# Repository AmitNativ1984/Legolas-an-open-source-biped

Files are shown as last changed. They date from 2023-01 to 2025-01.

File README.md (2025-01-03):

# Legolas - An Open Source Bipedal Robot

Legolas is a mini bipedal robot inspired by the Cassie by Agility Robotics. The project aims to provide an open-source platform for learning and applying reinforcement learning in robotics.

<p align="center">
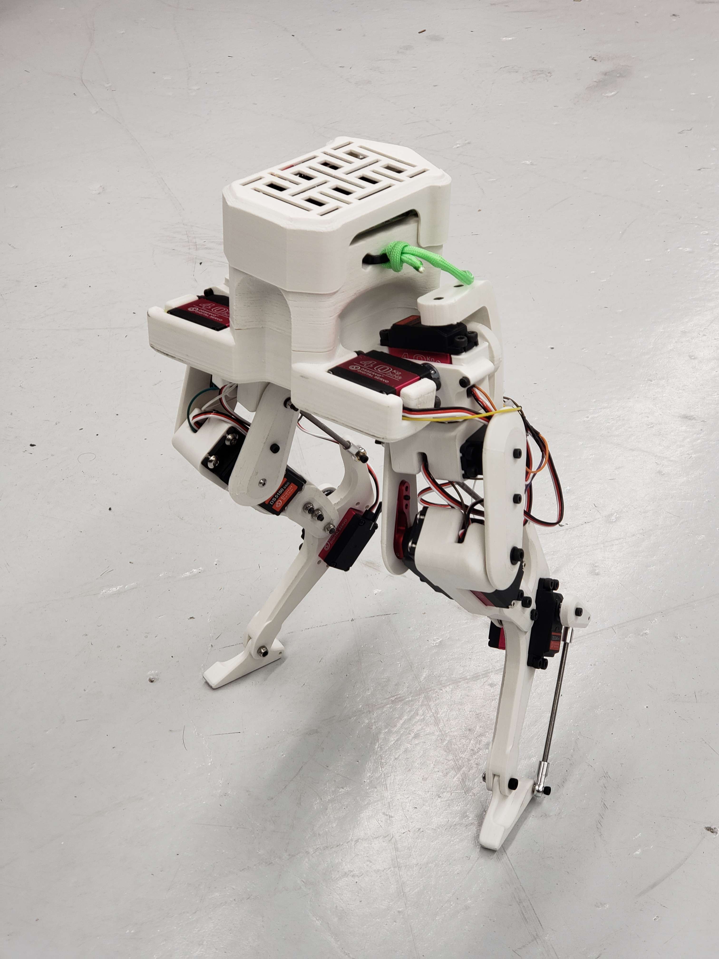
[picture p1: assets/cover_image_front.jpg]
  
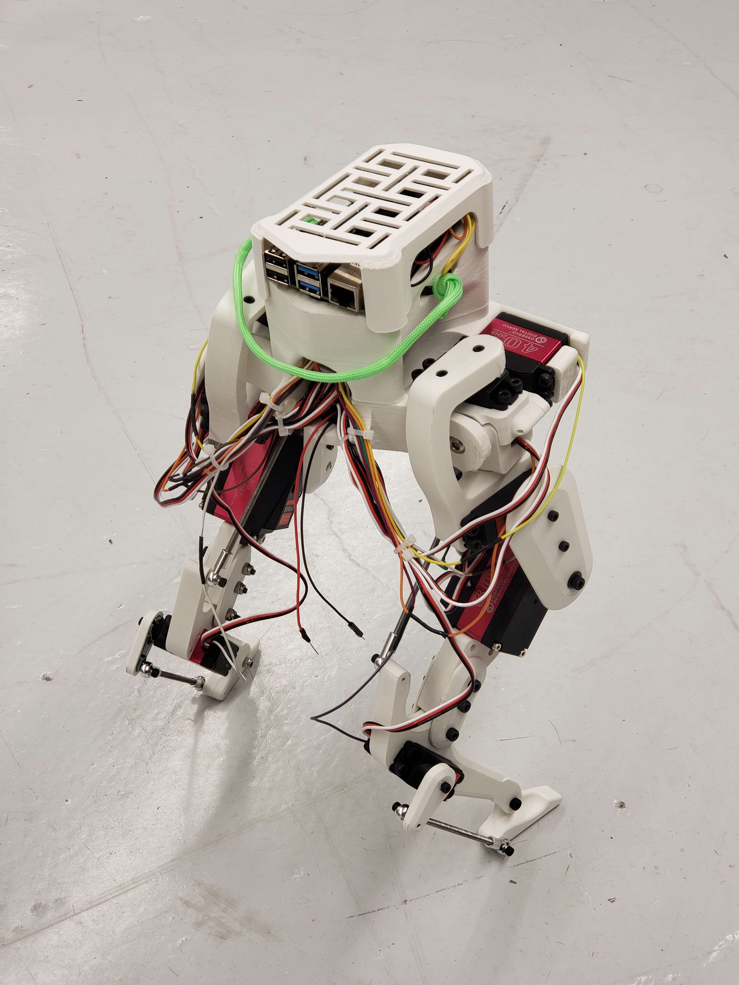
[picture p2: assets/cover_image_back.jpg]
  
</p>

<p align="center">
  <a href="assets/Walking_Test_3.mp4">Video 3</a>
</p>

## Repository Contents

This repository contains CAD files and 3D printing files for Legolas. 

The code for the robot is available at [Legolas Controller](https://github.com/daviddoo02/Legolas_Controller).

## Getting Started

1. **Clone this repository:**

    ```bash
    git clone https://github.com/daviddoo02/Legolas-an-open-source-biped/
    ```

2. **Modify the CAD files:**

    Modify the CAD files to fit your specific needs using Solidworks.

3. **3D Print your own robot:**

    Alternatively, use the provided STL files located in `CAD/Legolas/V2/STLs` to 3D print your own robot.

4. **Assemble the robot and have fun!**

## Required Materials

Materials and components used are listed and linked below.

### Main Body

| Part | Price | Purchased | Delivered |
|---|---| --- | --- |
| 1. [3D printing filament x 1 kg](https://www.amazon.com/dp/B089S1HB8K) | -- | :white_check_mark: | :white_check_mark: |
| 2. [Metric Nuts and Bolts](https://www.amazon.com/Assortment-M2-M3-M4-M5/dp/B0CBMMPPKF) | $12 | :white_check_mark: | :white_check_mark: |
| 3. [Metric Locknuts](https://www.amazon.com/dp/B0CHVTYLWC) | $7 | :white_check_mark: | :white_check_mark: |
| 4. [Thrust Bearings](https://www.amazon.com/gp/product/B08FHTD8VT) | $3 | :white_check_mark: | :white_check_mark: |
| 5. [Ball joint rod end](https://www.amazon.com/gp/product/B0828T1NNW) | $5 | :white_check_mark: | :white_check_mark: |
| 6. [M4 threaded rod](https://www.amazon.com/gp/product/B01MAYQ12S) | $3 | :white_check_mark: | :white_check_mark: |
| **Total** | **$30** |

### Electronics

| Part | Price | Purchased | Delivered |
| ---- | ----- | --- | --- |
| 1. [PCA9685 Servo Driver Board](https://www.amazon.com/gp/product/B07BRS249H) | $14 | :white_check_mark: | :white_check_mark: |
| 2. [40 kg Hobby Servos x 8](https://www.amazon.com/Servo-Torque-Waterproof-Degree-Compatible/dp/B0C95YMMQS) | $204 | :white_check_mark: | :white_check_mark: |
| 3. [80 kg Hobby Servos x 2](https://www.amazon.com/GoolRC-Digital-Torque-Waterproof-Replacements/dp/B0B5H4MWZG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) | $86 | :white_check_mark: | :white_check_mark: |
| 4. [MPU9255 IMU](https://www.amazon.com/-/he/dp/B0D4VYR8KF?ref=ppx_yo2ov_dt_b_fed_asin_title) | $25 | :white_check_mark: | :white_check_mark: |
| 5. [ADS1115 ADC](https://www.amazon.com/gp/product/B07VPFLSMX) | $16 | :white_check_mark: | :white_check_mark: |
| 6. [Jumper Wires](https://www.amazon.com/Elegoo-EL-CP-004-Multicolored-Breadboard-arduino/dp/B01EV70C78) | $7 | :white_check_mark: | :white_check_mark: |
| 7. [Power DIY Connector](https://www.amazon.com/dp/B09S3S6RYC) | $2 | :white_check_mark: | :white_check_mark: |
| 8. [USB C Connector](https://www.amazon.com/gp/product/B0CN64BR49/ref=ox_sc_act_title_1?smid=AJAM3W8TYBUO0&psc=1) | $15 | :white_check_mark: | :white_check_mark: |
| 9. [4 to 1 Wire Connector](https://www.amazon.com/dp/B0B28GNVGZ) | $2 | :white_check_mark: | :white_check_mark: |
| 10. shipping | $18 | :white_check_mark: | :ballot_box_with_check: |
| **Total** | **$389** |

### Compute
| Part | Price | Purchased | Delivered |
| ---- | ----- | --- | --- |
| 1. [jetson orin nano super developer kit](https://crg.co.il/product/nvidia-jetson-orin-nano-8gb-development-kit/) | $269 | :white_check_mark: | :white_check_mark:
| 2. Shipping | $13 | :white_check_mark: | :ballot_box_with_check: |
| 3. VAT | $48 | :white_check_mark: | :ballot_box_with_check: |
| **Total** | **$330** |

## Sensors
| Part | Price | Purchased |
| ---- | ----- | --- |
| 1. [Oak-D Light Depth Camera](https://shop.luxonis.com/products/oak-d-lite-1) | $149 |
| 2. [D435 Depth Camera](https://www.amazon.com/Intel-Depth-Camera-D435-Tracking/dp/B07B43WP7V) | $0 | :white_check_mark: |
| 3. [T-MINI-Plus Lidar TOF](https://www.amazon.com/dp/B0CCJRWKC5) | $79 |
| 4. [Logitech F710 Controller](https://www.amazon.com/Logitech-940-000117-Gamepad-F710/dp/B0041RR0TW) | $40 |

## Assembly Instruction

Instructions and examples for assembling Legolas will be added in future updates.

## License

This project is licensed under the MIT License - see the [LICENSE](LICENSE) file for details.

## Acknowledgments

- Inspired by the Cassie robot by Agility Robotics.
- Solidworks was used for the physical design of the robot.

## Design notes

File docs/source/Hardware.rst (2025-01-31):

Hardware
========

Setting up hardware

.. toctree::
    :hidden:
    :glob:

    Hardware/connecting-servos-to-jetson

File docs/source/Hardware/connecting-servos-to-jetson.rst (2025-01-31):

Connecting Servos with Jetson Orin Nano using PCA9685
=====================================================

This guide provides an overview of how to connect and control servo motors with the Jetson Orin Nano using the PCA9685 PWM driver.
It will cover the hardware connections, software setup, and code examples to control the servos, and provide a step-by-step guide to get you started.

Requirements
------------
- Jetson Orin Nano Dev Kit
- PCA9685 PWM driver
- Servo motors
- Jumper wires
- Power supply for servos (optional)

PCA9685 Board
-------------
The PCA9685 is a 16-channel, 12-bit PWM driver that can be used to control multiple servo motors with a single I2C interface.
**PMW** stands for Pulse Width Modulation. The input to a servo motor is a square wave signal with a fixed frequency (typically 50 Hz) and a variable duty cycle. 
The duty cycle determines the position (angle) of the servo motor. By changing the duty cycle, the servo motor changes its angular position, as quickly as possible.
As long as the duty cycle remains constant, the servo motor will maintain its position.

Servo Motor Animation

PCA9685 PWM Driver
    
The Jetson Orin Nano Dev Kit comes with a 40-Pin Expansion Header (see the `Jetson Orin Nano Pinout <https://developer.download.nvidia.com/assets/embedded/secure/jetson/orin_nano/docs/Jetson-Orin-Nano-DevKit-Carrier-Board-Specification_SP-11324-001_v1.3.pdf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>`_ for more details)
The output of the Jetson is a digital signal, transmitted over the I2C bus to the PCA9685 board, which then generates the PWM signals to control the servo motors.
Each servo motor connected to the PCA9685 board is controlled by one of the 16 available channels. 
The I2C signal sent to the PCA9685 includes the address of the PCA9685 board and the specific channel number to which the servo motor is connected. The PCA9685 then generates the corresponding PWM signal on that channel to control the servo motor.

For example, if you want to control a servo motor connected to channel 0, you would send the I2C signal to the PCA9685 with the address of the board and specify channel 0. Similarly, for a servo motor connected to channel 1, you would specify channel 1 in the I2C signal.

In the provided Python script, the `servo.Servo(pca.channels[0])` line creates a servo object for the servo motor connected to channel 0, and `servo.Servo(pca.channels[1])` creates a servo object for the servo motor connected to channel 1. You can create servo objects for other channels in a similar manner by specifying the appropriate channel number.

We can connect up to 12 servos to the PCA9685 board, and control them independently.
Here are the connections between the dev kit, and the PCA9685:

Pinout Table
------------
+-------------+-----------------------------------------------------------+--------------------------------------------+
| PCA9685 Pin | Description                                               | Jetson Orin Nano Dev Kit 40-Pin Expanstion |
+=============+===========================================================+============================================+
| GND         | Ground pin                                                | 6                                          |
+-------------+-----------------------------------------------------------+--------------------------------------------+
| OE          | OutputEnable. (LOW by defualt making all outputs enabled) | (?) Not connected                          |
+-------------+-----------------------------------------------------------+--------------------------------------------+
| SCL         | I2C **clock** pin                                         | 5 (I2C_SCL)                                |
+-------------+-----------------------------------------------------------+--------------------------------------------+
| SDA         | I2C **data** pin                                          | 3 (I2C_SDA)                                |
+-------------+-----------------------------------------------------------+--------------------------------------------+
| VCC         | Logic power pin (3V-5V)                                   | 1 (3.3V-5V)                                |
+-------------+-----------------------------------------------------------+--------------------------------------------+
| V+          | External Servo power pin (5V-6V)                          | 2 (Main 5.0V supply)                       |
+-------------+-----------------------------------------------------------+--------------------------------------------+

Jetson Orin Nano 40 Pin Expansion Header

3. **Install Required Libraries:**
    - Install the Adafruit PCA9685 library on the Jetson Orin Nano using pip:
      
      .. code-block:: bash

         pip install adafruit-circuitpython-pca9685

4. **Find the address of the PCA9685 board:**
    - The PCA9685 board has a default I2C address of `0x40`. However, if you have multiple PCA9685 boards connected to the same I2C bus, you may need to change the address of the board to avoid conflicts.
    - To find the address of the PCA9685 board, run the following command on the Jetson Orin Nano:
      
      .. code-block:: bash

         sudo i2cdetect -y -r 1

    - The output will show the I2C addresses of all devices connected to the I2C bus. Look for the address `0x40` in the output to find the address of the PCA9685 board.

5. **Write and Run the Control Script:**
   - Below is an example python script, that will control two servos connected to channes 0 and 1 of the PCA9685 board. The script uses a simple PWM frequency of 50 Hz, and moves `servo0` to 90 degrees, and `servo1` to 45 degrees. You can modify the angles and channels to control more servos.
    
   .. code-block:: python

      import time
      from board import SCL, SDA
      import busio
      from adafruit_pca9685 import PCA9685
      from adafruit_motor import servo

      # Create the I2C bus interface
      i2c_bus = busio.I2C(SCL, SDA)

      # Create a simple PCA9685 class instance
      pca = PCA9685(i2c_bus)
      pca.frequency = 50

      # Create a servo object for each servo
      servo0 = servo.Servo(pca.channels[0])
      servo1 = servo.Servo(pca.channels[1])

      # Move servos to different angles
      servo0.angle = 90
      time.sleep(1)
      servo1.angle = 45
      time.sleep(1)

      # Cleanup
      pca.deinit()

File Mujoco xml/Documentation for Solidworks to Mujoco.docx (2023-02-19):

Documentation for Solidworks to Mujoco:

1. Exporting from Solidworks using SW2URDF:
  a. Step 1: Download SW2URDF extension
    i. Repo: https://github.com/ros/solidworks_urdf_exporter/releases
  b. Step 2: Assigning frames to your robot
    i. (170) Frame Assignment For Robotic Manipulators - Direct Kinematics I - YouTube (https://www.youtube.com/watch?v=fNIyNF87q9I&t=244s)
    ii. ^ this video should give you a good idea of what assigning frames is and how to know where to place your frames.
    iii. Use the Reference geometry → Coordinate system tool in Solidworks.
      1. A useful tip: Point your coordinate systems toward each other if possible – this will make it easier to code in mujoco later.
  c. Step 3: Using the extension
    i. Follow this video tutorial: https://www.youtube.com/watch?v=ge3P307TgJI
    ii. Now you should have a folder with the URDF of your robot.
2. Accessing the URDF and verifying the urdf:
  a. Ref:
    i. https://mujoco.readthedocs.io/en/latest/modeling.html#curdf
    ii. urdf - ROS Wiki (http://wiki.ros.org/urdf)
  b. Step 1: Checking if your URDF generated correctly:
    i. Add the mujoco extension after robot name like so:

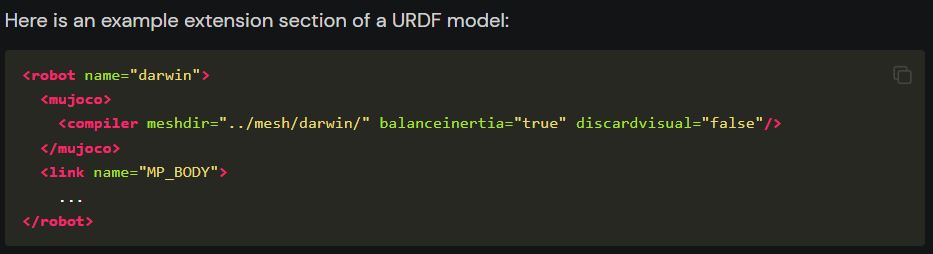
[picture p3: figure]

  c. Step 2: Check the URDF for collision/joint problems:
    i. After you add the extension, you should be able to drag and drop the file into mujoco and 2 things can happen:
      1. Everything runs < less interesting
      2. Everything runs itself apart < more interesting
        a. If this was the case, you could be running into a collision issue.
        b. You can confirm this by tapping F to toggle the forces vectors and H to toggle the convex hull

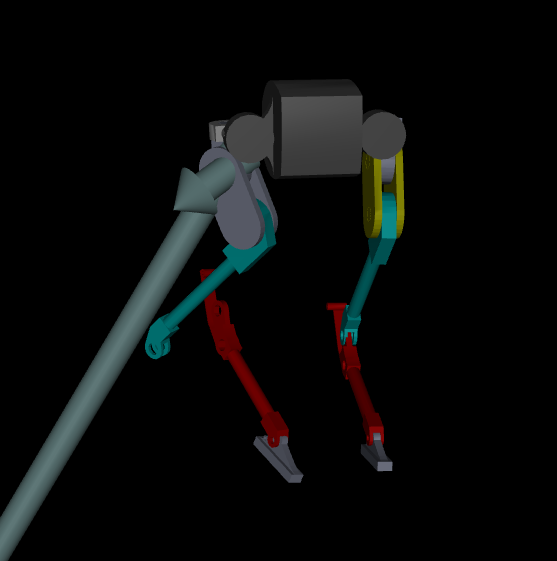
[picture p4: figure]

          ii. So, as you can see, there is a huge force coming off the body and the knee joint not being connected.
    ii. Fixing Joints:
      1. Go back to Solidworks and check how the urdf was generated, make sure all the frames and joint types are correct and regenerate the urdf.
    iii. Fixing collision:
      1. Check which part is colliding by hitting the H-key on your keyboard.
        a. Note: if a collision geometry was not specified, mujoco will automatically generate it, but it messes up sometimes.
      2. Solution: in the URDF, replace the collision mesh with something else by changing the name of the collision geometry mesh to the new mesh.
  d. Step 3: Verifying your URDF on Linux:
    i. Use the following command on Linux terminal to verify the URDF:
      1. rosrun urdfdom check_urdf /path2model/<model>.urdf
    ii. This should output the kinematic tree of your robot.

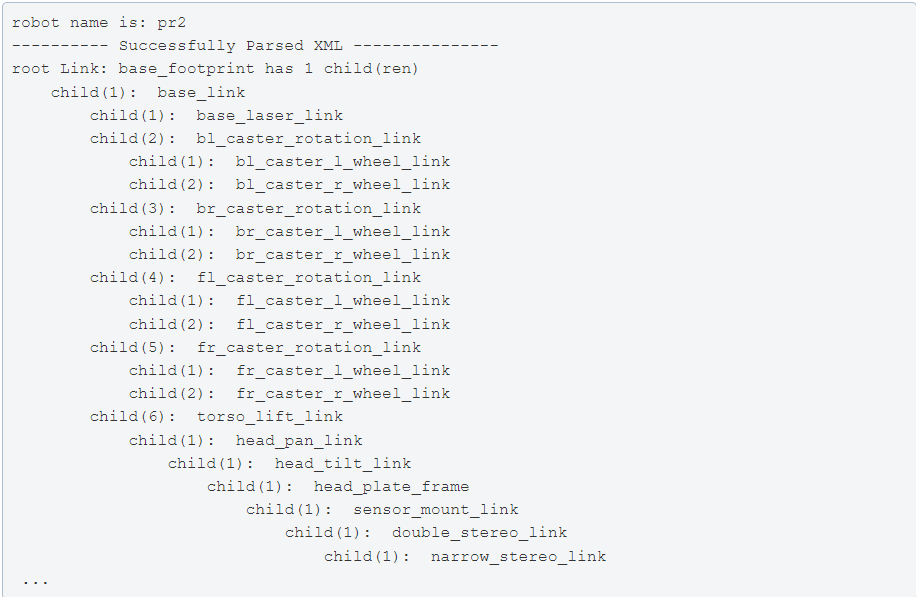
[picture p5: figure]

3. Converting URDF to MUJOCO xml:
  a. Ref:
    i. wangcongrobot/dual_ur5_husky_mujoco: Dual UR5 Husky Robot MuJoCo Model (github.com) (https://github.com/wangcongrobot/dual_ur5_husky_mujoco)
  b. Enter the path ~/mujoco/mujoco200/bin first and run command below:
  c. Convert the urdf:
    i. compile /path/to/model.urdf /path/to/model.xml
  d. Test:
    i. mujoco200/bin$ ./simulate /path/to/model.xml

Congratulations! You are now able to run mujoco with your robot design! Add more mujoco tags as needed

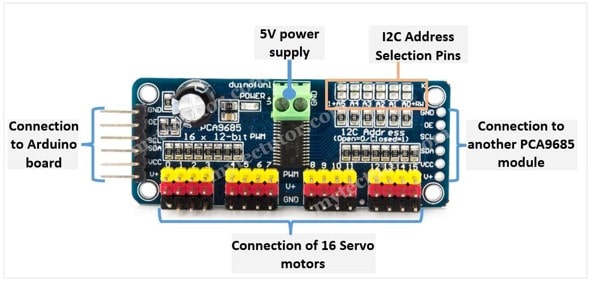
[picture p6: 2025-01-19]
assets/PCA9685-16-channel-servo-motor-driver-pinout.jpg

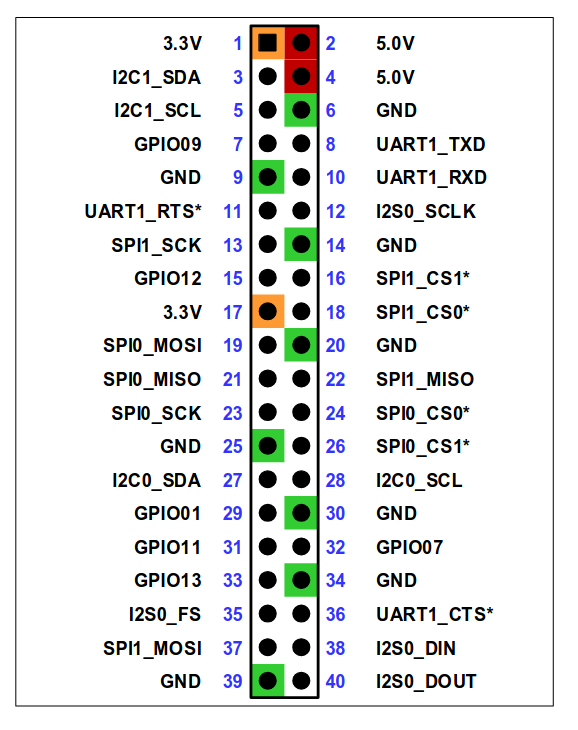
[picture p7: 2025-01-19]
assets/Jetson-orin-nano-40-pin-connections.png

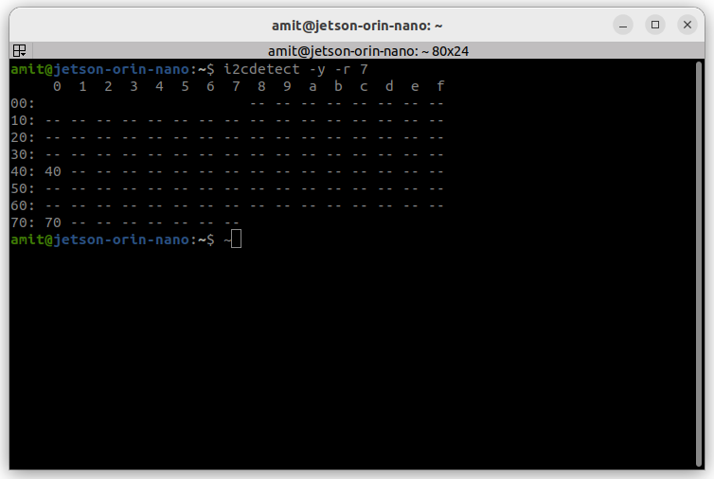
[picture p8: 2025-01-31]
docs/source/_static/i2cdetect-7-pca9685.png

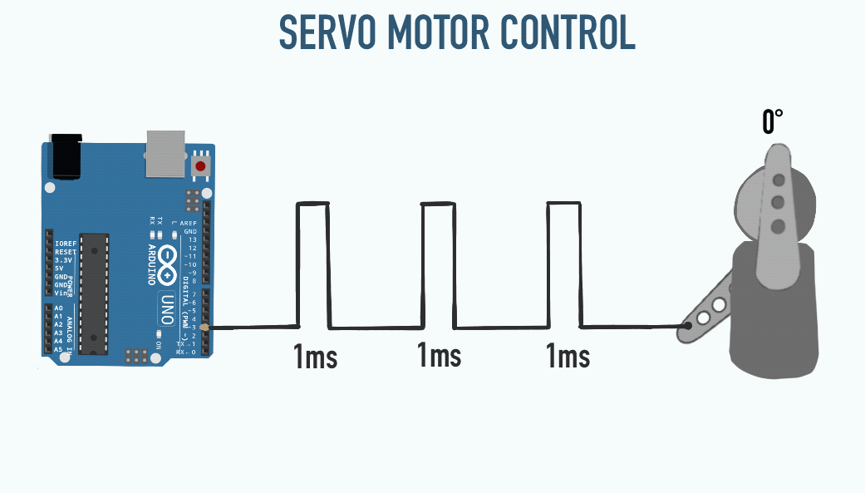
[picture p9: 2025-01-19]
assets/ServoGif.gif

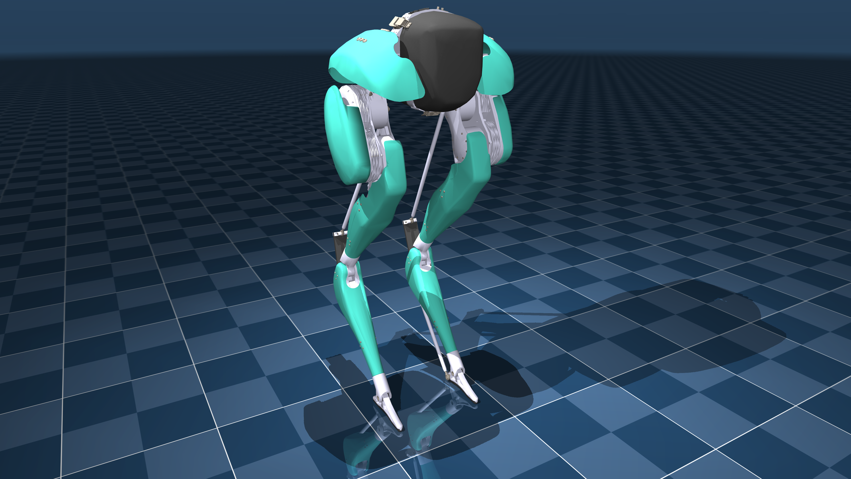
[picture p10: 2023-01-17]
Mujoco xml/References/agility_cassie/cassie.png

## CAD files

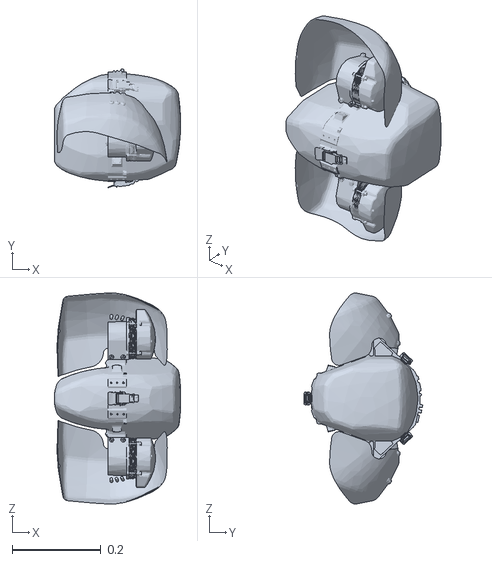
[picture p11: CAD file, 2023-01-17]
Mujoco xml/References/agility_cassie/assets/pelvis.obj
0.284 x 0.267 x 0.474

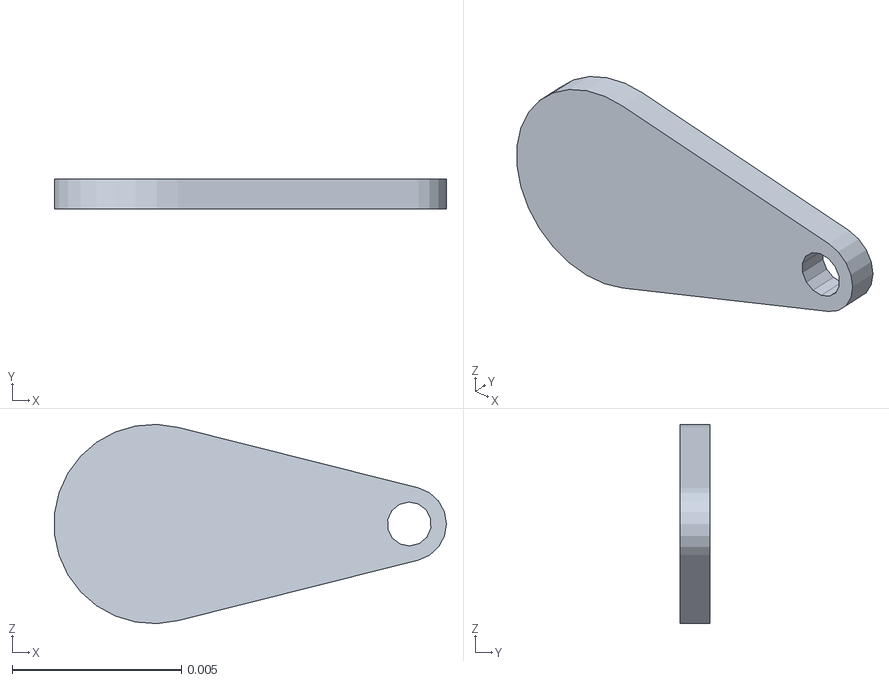
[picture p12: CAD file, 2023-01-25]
Working Mk 5/meshes/R_Servo_collision.STL
0.0116 x 0.000898 x 0.00589

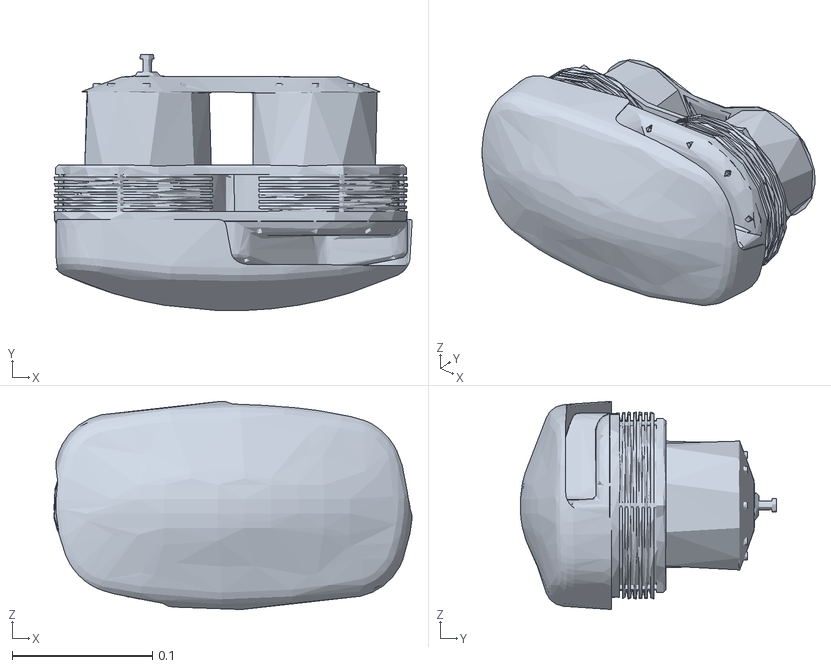
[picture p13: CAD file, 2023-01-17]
Mujoco xml/References/agility_cassie/assets/hip-pitch.obj
0.256 x 0.183 x 0.149

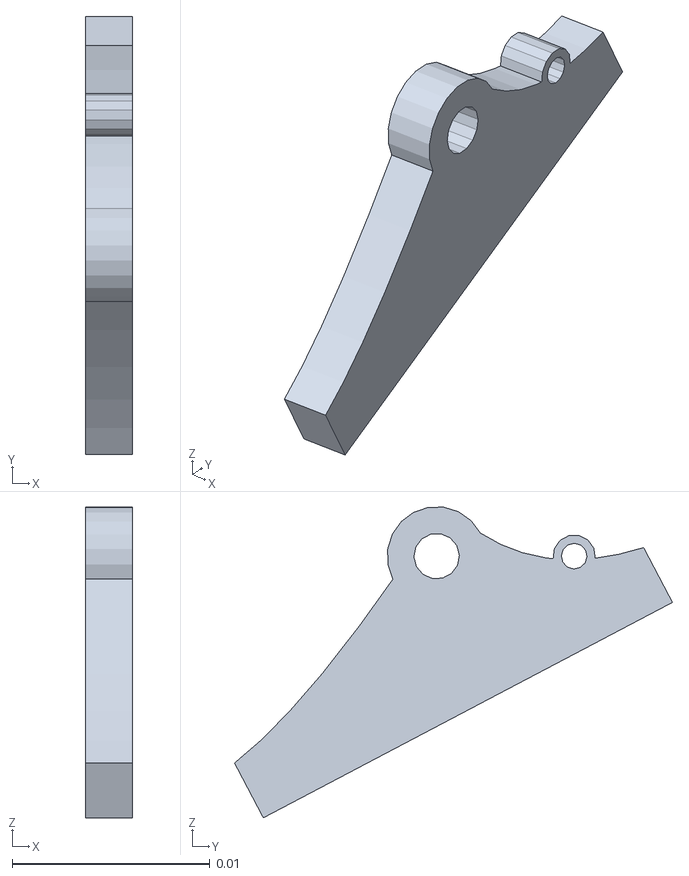
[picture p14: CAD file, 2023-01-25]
Working Mk 5/meshes/R_Foot_collision.STL
0.0024 x 0.0221 x 0.0157

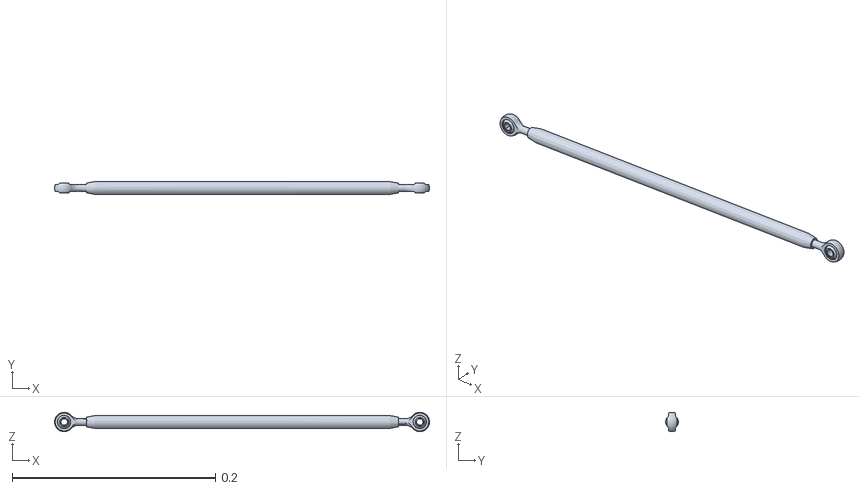
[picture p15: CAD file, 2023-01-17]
Mujoco xml/References/agility_cassie/assets/plantar-rod.obj
0.369 x 0.0127 x 0.0191

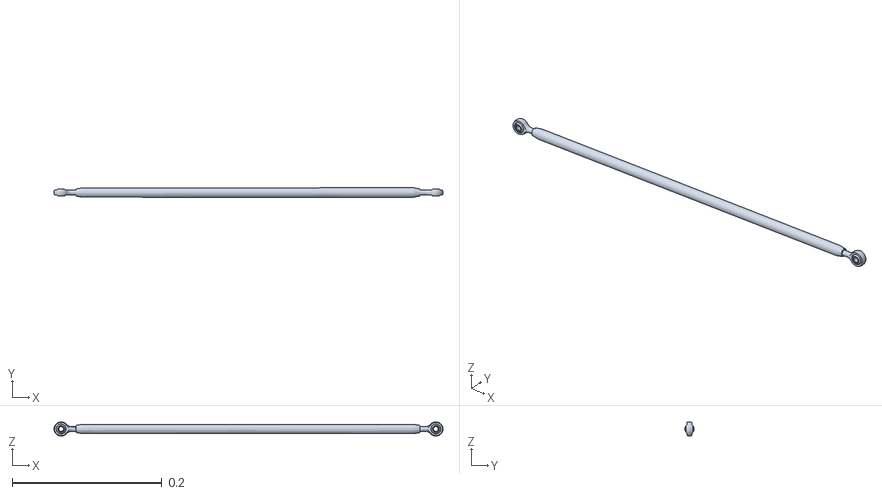
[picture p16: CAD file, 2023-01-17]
Mujoco xml/References/agility_cassie/assets/achilles-rod.obj
0.52 x 0.0128 x 0.0191

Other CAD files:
CAD Tree/David's cardboard box/Assembly 1.SLDASM
CAD/Test_Bench/Test_Bench_Mk2.SLDASM
CAD/Servo and electronics/servo.SLDASM
CAD/Legolas/V3/Foot v3.SLDPRT
CAD/Servo and electronics/MPU 6050 IMU.SLDPRT
CAD/Legolas/V3/Foreleg v3.SLDPRT
CAD/Servo and electronics/Raspberry Pi 4 Model B.SLDPRT
CAD/Legolas/V3/Shin v3.SLDPRT
CAD/Servo and electronics/M4 Ball Joint Rod End.SLDPRT
Working Mk 5/meshes/L_Foot_collision.STL
CAD/Legolas/V3/Servo Cover v3.SLDPRT
CAD/Servo and electronics/Mirror40 kg Servo.SLDPRT
CAD/Legolas/V1/Full_Assembly.SLDASM
CAD/Legolas/V1/Legolas_v1.SLDASM
CAD/Legolas/V2/Foot.SLDPRT
CAD/Legolas/V2/Foreleg.SLDPRT
CAD/Legolas/V2/Full Assembly.SLDASM
CAD/Legolas/V2/Hip Pitch.SLDPRT
CAD/Legolas/V2/Hip Roll.SLDPRT
CAD/Legolas/V2/Hip Yaw.SLDPRT
CAD/Legolas/V2/Legolas V2 Left Leg.SLDASM
CAD/Legolas/V2/M4 Linkage 1.SLDASM
CAD/Legolas/V2/M4 Linkage 2.SLDASM
CAD/Legolas/V2/STLs/Foot.STL
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

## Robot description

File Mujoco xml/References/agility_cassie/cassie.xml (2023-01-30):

<mujoco model="cassie">
  <compiler eulerseq="zyx" meshdir="assets" texturedir="assets" autolimits="true"/>

  <option timestep="0.0005"/>
  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

  <default>
    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
    <equality solref="0.005 1"/>
    <default class="cassie">
      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
    </default>
    <default class="collision">
      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
      <default class="collision-left">
        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
      </default>
      <default class="collision-right">
        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
      </default>
    </default>
  </default>

  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

  <worldbody>
    <light name="spotlight" mode="targetbodycom" target="cassie-pelvis" pos="0 -1 2"/>
    <body name="cassie-pelvis" pos="0 0 1.1" childclass="cassie">
      <camera name="track" pos="0 -3 1" zaxis="0 -1 0.5" mode="track"/>
      <inertial pos="0.05066 0.000346 0.02841" mass="10.33" fullinertia="0.085821 0.049222 0.08626 1.276e-05 -0.00016022 -0.000414"/>

      <freejoint/>

      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
      
      <body name="left-hip-roll" pos="0.021 0.135 0" xyaxes="0 0 -1 0 1 0">
        <inertial pos="-0.01793 0.0001 -0.04428" mass="1.82" fullinertia="0.003431 0.003793 0.002135 -6.65e-07 -0.00084 3.99e-06"/>
        <joint name="left-hip-roll" type="hinge" range="-15 22.5" damping="1" armature="0.038125"/>
        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
        <body name="left-hip-yaw" pos="0 0 -0.07" xyaxes="0 0 1 0 1 0">
          <inertial pos="0 -1e-05 -0.034277" mass="1.171" fullinertia="0.002443 0.002803 0.000842 -4e-08 2.462e-07 -2.71e-08"/>
          <joint name="left-hip-yaw" type="hinge" range="-22.5 22.5" damping="1" armature="0.038125"/>
          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
          <body name="left-hip-pitch" pos="0 0 -0.09" xyaxes="0 0 -1 1 0 0">
            <inertial pos="0.05946 5e-05 -0.03581" mass="5.52" fullinertia="0.010898 0.029714 0.030257 -0.0002669 -5.721e-05 9.17e-06"/>
            <joint name="left-hip-pitch" type="hinge" range="-50 80" damping="1" armature="0.09344"/>
            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
            <body name="left-achilles-rod" pos="0 0 0.045" xyaxes="0.7922 -0.60599 -0.072096 0.60349 0.79547 -0.054922">
              <inertial pos="0.24719 0 0" mass="0.1567" fullinertia="3.754e-06 0.004487 0.004488 -3.74e-08 -1.61e-08 0"/>
              <joint name="left-achilles-rod" type="ball" damping="0.01"/>
              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
            </body>
            <body name="left-knee" pos="0.12 0 0.0045" xyaxes="0.70711 -0.70711 0 0.70711 0.70711 0">
              <inertial pos="0.023 0.03207 -0.002181" mass="0.7578" fullinertia="0.001376 0.0010335 0.0021637 -0.00039744 -4.085e-05 -5.374e-05"/>
              <joint name="left-knee" type="hinge" ref="-45" range="-164 -37" damping="1" armature="0.09344"/>
              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
              <body name="left-knee-spring" pos="0.06068 0.08241 0">
                <inertial pos="0.0836 0.0034 0" mass="0.186" fullinertia="5.215e-05 0.00041205 0.0003669 6.87e-06 0 0"/>
                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
              </body>
              <body name="left-shin" pos="0.06068 0.04741 0">
                <inertial pos="0.18338 0.001169 0.0002123" mass="0.577" fullinertia="0.00035939 0.014728 0.014707 -0.00020981 2.266e-05 -1.2e-07"/>
                <joint name="left-shin" type="hinge" range="-20 20" stiffness="1500" damping="0.1"/>
                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
                <body name="left-tarsus" pos="0.43476 0.02 0" xyaxes="0.52992 0.84805 0 -0.84805 0.52992 0">
                  <inertial pos="0.11046 -0.03058 -0.00131" mass="0.782" fullinertia="0.00039238 0.013595 0.013674 0.00023651 -4.987e-05 -4.82e-06"/>
                  <joint name="left-tarsus" type="hinge" ref="58" range="50 170" damping="0.1"/>
                  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
                  <body name="left-heel-spring" pos="-0.01269 -0.03059 0.00092" xyaxes="-0.91211 0.40829 0.036948 -0.40992 -0.90952 -0.068841">
                    <inertial pos="0.081 0.0022 0" mass="0.126" fullinertia="2.959e-05 0.00022231 0.0002007 7.15e-06 -6e-07 1e-07"/>
                    <joint name="left-heel-spring" type="hinge" stiffness="1250"/>
                    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
                  </body>
                  <body name="left-foot-crank" pos="0.058 -0.034 0.02275">
                    <inertial pos="0.00493 2e-05 -0.00215" mass="0.1261" fullinertia="2.6941e-05 4.9621e-05 6.3362e-05 -2.1e-09 -3.9623e-06 -1.09e-08"/>
                    <joint name="left-foot-crank" type="hinge" range="-140 -30" damping="1"/>
                    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
                    <body name="left-plantar-rod" pos="0.055 0 -0.00791">
                      <inertial pos="0.17792 0 0" mass="0.1186" fullinertia="2.779e-06 0.001774 0.001775 -2.34e-08 -8.1e-09 0"/>
                      <joint name="left-plantar-rod" type="hinge"/>
                      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
                    </body>
                  </body>
                  <body name="left-foot" pos="0.408 -0.04 0">
                    <inertial pos="0.00474 0.02748 -0.00014" mass="0.1498" fullinertia="0.00017388 0.00016793 0.00033261 0.00011814 1.36e-06 -4e-07"/>
                    <joint name="left-foot" type="hinge" range="-140 -30" damping="1" armature="0.01225"/>
                    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
                  </body>
                </body>
              </body>
            </body>
          </body>
        </body>
      </body>
      <body name="right-hip-roll" pos="0.021 -0.135 0" xyaxes="0 0 -1 0 1 0">
        <inertial pos="-0.01793 0.0001 -0.04428" mass="1.82" fullinertia="0.003431 0.003793 0.002135 6.65e-07 -0.00084 -3.99e-06"/>
        <joint name="right-hip-roll" type="hinge" range="-22.5 15" damping="1" armature="0.038125"/>
        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
        <body name="right-hip-yaw" pos="0 0 -0.07" xyaxes="0 0 1 0 1 0">
          <inertial pos="0 1e-05 -0.034277" mass="1.171" fullinertia="0.002443 0.002803 0.000842 4e-08 2.462e-07 2.71e-08"/>
          <joint name="right-hip-yaw" type="hinge" range="-22.5 22.5" damping="1" armature="0.038125"/>
          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
          <body name="right-hip-pitch" pos="0 0 -0.09" xyaxes="0 0 -1 1 0 0">
            <inertial pos="0.05946 5e-05 0.03581" mass="5.52" fullinertia="0.010898 0.029714 0.030257 -0.0002669 5.721e-05 -9.17e-06"/>
            <joint name="right-hip-pitch" type="hinge" range="-50 80" damping="1" armature="0.09344"/>
            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
            <body name="right-achilles-rod" pos="0 0 -0.045" xyaxes="0.7922 -0.60599 0.072096 0.60349 0.79547 0.054922">
              <inertial pos="0.24719 0 0" mass="0.1567" fullinertia="3.754e-06 0.004487 0.004488 -3.74e-08 1.61e-08 0"/>
              <joint name="right-achilles-rod" type="ball" damping="0.01"/>
              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
            </body>
            <body name="right-knee" pos="0.12 0 -0.0045" xyaxes="0.70711 -0.70711 0 0.70711 0.70711 0">
              <inertial pos="0.023 0.03207 0.002181" mass="0.7578" fullinertia="0.001376 0.0010335 0.0021637 -0.00039744 4.085e-05 5.374e-05"/>
              <joint name="right-knee" type="hinge" ref="-45" range="-164 -37" damping="1" armature="0.09344"/>
              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
              <body name="right-knee-spring" pos="0.06068 0.08241 0">
                <inertial pos="0.0836 0.0034 0" mass="0.186" fullinertia="5.215e-05 0.00041205 0.0003669 6.87e-06 0 0"/>
                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
              </body>
              <body name="right-shin" pos="0.06068 0.04741 0">
                <inertial pos="0.18338 0.001169 -0.0002123" mass="0.577" fullinertia="0.00035939 0.014728 0.014707 -0.00020981 -2.266e-05 1.2e-07"/>
                <joint name="right-shin" type="hinge" range="-20 20" stiffness="1500" damping="0.1"/>
                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
                <body name="right-tarsus" pos="0.43476 0.02 0" xyaxes="0.52992 0.84805 0 -0.84805 0.52992 0">
                  <inertial pos="0.11046 -0.03058 0.00131" mass="0.782" fullinertia="0.00039238 0.013595 0.013674 0.00023651 4.987e-05 4.82e-06"/>
                  <joint name="right-tarsus" type="hinge" ref="58" range="50 170" damping="0.1"/>
                  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
                  <body name="right-heel-spring" pos="-0.01269 -0.03059 -0.00092" xyaxes="-0.91211 0.40829 -0.036948 -0.40992 -0.90952 0.068841">
                    <inertial pos="0.081 0.0022 0" mass="0.126" fullinertia="2.959e-05 0.00022231 0.0002007 7.15e-06 6e-07 -1e-07"/>
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

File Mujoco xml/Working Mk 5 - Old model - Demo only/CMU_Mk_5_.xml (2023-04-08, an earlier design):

<mujoco model="CMU Mk 5">
  <compiler angle="radian" meshdir="meshes/" autolimits="true"/>
  
  <option timestep="0.005" gravity="0 0 0"/>

  <default/>

  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
  
  <worldbody>
    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
    
    <light name="spotlight" mode="targetbodycom" target="base link" pos="0 6 4" castshadow="false"/>
    
    <body name="base link" pos="0 0 .2">    
      <camera name="track" pos="0 -3 1" zaxis="0 -1 0.5" mode="track"/>
      <inertial pos="0 0 0" mass="0.0299227589680342" fullinertia="4.64430780114595E-06 4.78982197003375E-06 5.96248441172554E-06 -7.0005651433527E-12 1.45948993644989E-11 -7.65792898200085E-08"/>
      
      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      
      
      <body name="R_Hip_1" pos="0.021005 0 0" quat="0.706765 0.706768 -0.0219327 0.0219327">
        <inertial pos="-3.00471e-07 -4.83658e-06 0.00581975" quat="0.707107 0 0 0.707107" mass="0.000490673" diaginertia="1.27003e-08 9.79961e-09 4.84291e-09"/>
        
        <joint name="R_Hip_1" type="hinge" pos="0 0 0" axis="0 0 1"/>
        
        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
        
        <body name="R_Hip_2" pos="0 0 0.0076962" quat="0.529268 0.52927 0.468907 -0.468908">
          <inertial pos="-1.39156e-10 -1.14679e-09 0.0107683" quat="0.707107 0 0 0.707107" mass="0.00100456" diaginertia="4.56705e-08 3.43974e-08 1.53565e-08"/>
          
          <joint name="R_Hip_2" type="hinge" pos="0 0 0" axis="0 0 1"/>
          
          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
          
          <body name="R_Thigh" pos="0 0 0.013139" quat="0.397507 0.584796 0.584798 0.397509">
            <inertial pos="3.40459e-05 0.009 0" quat="0.707107 0.707107 0 0" mass="0.00259524" diaginertia="2.57116e-07 2.17945e-07 5.47709e-08"/>
            
            <joint name="R_Thigh" type="hinge" pos="0 0 0" axis="-1 0 0"/>
            
            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
            
            <body name="R_Foreleg" pos="0 0.018 0" quat="-1.92102e-06 3.13083e-06 -0.852343 0.522982">
              <inertial pos="0 0.0208617 -0.00148561" quat="0.684738 0.728789 0 0" mass="0.00244939" diaginertia="1.23016e-06 1.2006e-06 3.92157e-08"/>
              
              <joint name="R_Foreleg" type="hinge" pos="0 0 0" axis="-1 0 0" limited="true" range="-5 100" damping="0"/>
              
              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

              <body name="R_Shin" pos="0 0.064516 0" quat="0.868737 -0.495274 0 0">
                <inertial pos="4.16582e-05 0.0220307 -0.00550832" quat="0.819399 0.572189 -0.0177322 0.029512" mass="0.00129205" diaginertia="4.33834e-07 4.29412e-07 9.31982e-09"/>
                
                <joint name="R_Shin" type="hinge" pos="0 0 0" axis="-1 0 0"/>
                
                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

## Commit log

2023-01-08 Updated Mk 3 URDF
    [CMU.urdf, Cassie_mock_up_mjc.xml]
2023-01-08 Added mujoco extension
    [CMU3.urdf]
2023-01-09 Fixed Collision problem - added documentation
    [Base Link.SLDPRT, CMU.urdf, CMU3.urdf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]
2023-01-24 Updated CADs
    Updated CADs, include linkages and servos
    [CMU.SLDASM, ForeShin.SLDPRT, L Feet.STL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]
2023-01-24 New URDF with more Links
    New links
    [CMU.SLDASM, CMU.SLDASM.csv, CMU.SLDASM.urdf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]
2023-01-25 URDF Mk 5 completed
    [CMU MK 4.urdf, CMU Mk 5.csv, CMU Mk 5.urdf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]
2023-01-25 Added Collision Files
    [L_Foot_collision.STL, L_Servo_collision.stl, R_Foot_collision.stl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]
2023-01-25 Fixing Collision
    [R_Servo_collision.stl]
2023-01-30 Added equality constraint
    [CMU.SLDASM, L_Foot.STL, L_Foot_collision.STL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]
2023-02-03 Created CAD Folder
    [leg_v2.SLDASM]
2023-02-03 Renamed servo file
2023-04-02 Lower Leg CAD
    Remade the foot up to the knee
    [Base Link.SLDPRT, CMU.SLDASM, Foot.SLDPRT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]
2023-04-02 Sophia's stuff
    [NewTestAssem.SLDASM, new_foot.SLDPRT]
2023-04-08 Added David's RL stuff
    [CMU.SLDASM]
2023-04-22 Add files via upload
    Is it back again?
    [Bar Attachment.SLDPRT, Bar Interface.SLDPRT, Hip Assembly.SLDASM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]
2023-05-17 Reorganized and added some stuff
    Added some stuff
    [60355K505_Ball Bearing.SLDPRT, Assembly 1.SLDASM, Bar Attachment.SLDPRT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]
2023-05-19 New Assembly in David's cardboard boxf
    dsa
    [Newer_New_Shin_Upper.SLDPRT, new_thigh.SLDPRT]
2023-05-22 Updated assembly
    [M4 Ball Joint Rod End.SLDPRT, M4 Connecting Rod.SLDPRT, M5 Ball Joint Rod End.SLDPRT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]
2023-05-24 Finished Prelim Assembly
    [Test Bench Assembly.SLDASM]
2023-06-01 First leg prototype done!
    [Adaptor.STL, Ankle x 2.STL, Foot A.STL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]
2023-06-03 Updated Assembly 1
    [Foreleg upper A.STL, Hip 1 A.STL, Hip 1 B.STL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]
2023-06-26 updated parts
    [Foreleg lower x 2.STL, Shin A.STL, Shin B.STL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]
2023-07-01 Updated CAD w thrust bearings
    [Ankle v2.STL, Base Link.SLDPRT, CMU.SLDASM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]
2023-07-12 URDF Testing
    [Adaptor.STL, Ankle v2.STL, Ankle x 2.STL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]
2023-07-14 Clean up!
    [Base Link.SLDPRT, Base.SLDPRT, CMU MK 4.urdf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]
2023-08-20 Updated Cad with 80 kg servo
    [80kg_servo.SLDPRT, 80kg_servo_arm.SLDPRT, Foreleg upper mk 2 A.STL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]
2023-09-23 Updated CAD
    [60355K505_Ball Bearing.SLDPRT, ADS1115.SLDPRT, Base Link.SLDPRT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]
2023-09-23 Updated CAD again
    [Foot.SLDPRT, Test_Bench_Mk2.SLDASM]
2023-11-08 Cleaned up + added README
    [80kg_servo.SLDPRT, 80kg_servo_arm.SLDPRT, ADS1115.SLDPRT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]
2024-01-15 V2 CAD updated!
    [achilles-rod.obj, cassie.xml, foot-crank.obj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]
2025-01-20 enhanced documentation for PCA9685 servo control, added detailed explanations and updated images
2025-01-20 update image link for Jetson Orin Nano 40 Pin Expansion Header in documentation
2025-01-20 corrected servo connection limit in documentation and updated image alignment
2025-01-20 adjust image height for Jetson Orin Nano documentation
2025-01-20 update image alignment for Jetson Orin Nano documentation
2025-01-20 format code block for servo control script in documentation
2025-01-20 format code block indentation for servo control script in documentation
2025-01-20 correct code block directive case for Python script in documentation
2025-01-20 improve documentation for servo control script with additional context and corrected indentation
2025-01-20 fix documentation formatting for bash code block in servo control guide
2025-01-20 fix indentation for pip install command in servo control documentation
2025-01-28 Added i2c permission to dockerfile thorugh --group-add
2025-01-31 adding i2cdetect terminal output
2025-02-07 Ignore CAD/ directory
2025-02-07 Track CAD/ files with Git LFS
2025-02-07 Add CAD files for Legolas V2 and V3, and update .gitattributes for LFS tracking
    [40 kg Servo Arm.SLDPRT, 40 kg Servo.SLDPRT, 80kg_servo.SLDPRT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]
